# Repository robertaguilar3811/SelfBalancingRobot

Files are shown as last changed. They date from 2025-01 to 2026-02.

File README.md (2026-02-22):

# Self Balancing Robot

> **Status:** Active development  
> This project is under active development and is being used as a platform to study
industrial-style motion control, feedback systems, and real-time architecture.
---

## Overview

A two-wheeled self-balancing robot built as a controls engineering exercise, with emphasis on deterministic control loops, state-based logic, and clean separation of real-time and supervisory tasks.

The design philosophy mirrors industrial automation: clearly defined I/O, cyclic execution, and closed-loop control driven by sensor feedback applied here to a dynamic, inherently unstable mechanical system.

---

## Mechanical Design

The frame consists of stacked 3D-printed PLA plates constrained by 3/8"-16 threaded rods, forming a rigid, modular structure that allows:

- Rapid iteration and reconfiguration
- Controlled center-of-mass adjustment
- Easy access to wiring, sensors, and drive components

---

## Hardware

| Component | Role |
|---|---|
| Teensy 4.1 | Low-level motor controller |
| Raspberry Pi 4 | Soft PLC — runs CodeSys runtime |
| MPU6050 IMU | Orientation and angular rate feedback |
| DC Gear Motors | Primary actuators |

The Teensy handles time-critical motor control while the Raspberry Pi runs a CodeSys soft PLC runtime, handling supervisory logic, configuration, and monitoring a direct implementation of a PLC + distributed I/O architecture found in industrial systems.

---

## Control Strategy

The robot stabilizes using a closed-loop feedback controller driven by tilt angle and angular velocity from the IMU. Key design principles include:

- Deterministic cyclic execution
- Tunable feedback control loop
- Clear separation of control and supervisory logic
- Defined safe startup and shutdown behavior

Currently implemented as a PID controller, with planned migration to more advanced control strategies as the platform matures.

---

## Software Structure

Control software is organized around industrial automation principles:

- Cyclic main control loop with fixed execution timing
- Explicit state machine (Init → Idle → Enable → Run → Fault)
- Deterministic sensor acquisition and actuator output
- Parameterized gains and configurable limits

Monitoring and tuning are handled outside the real-time loop to preserve control determinism.

---

## System State Machine

| State | Description |
|---|---|
| Init | Hardware and sensor validation |
| Idle | Motors disabled, system safe |
| Enable | Control loop armed, awaiting command |
| Run | Active balancing control |
| Fault | Safe shutdown on error or instability |

---

## Planned Improvements

- Port control logic concepts to PLC platforms (Structured Text / IEC 61131-3)
- Gain scheduling and advanced control strategies
- Enhanced fault diagnostics and recovery
- Industrial HMI or supervisory system integration

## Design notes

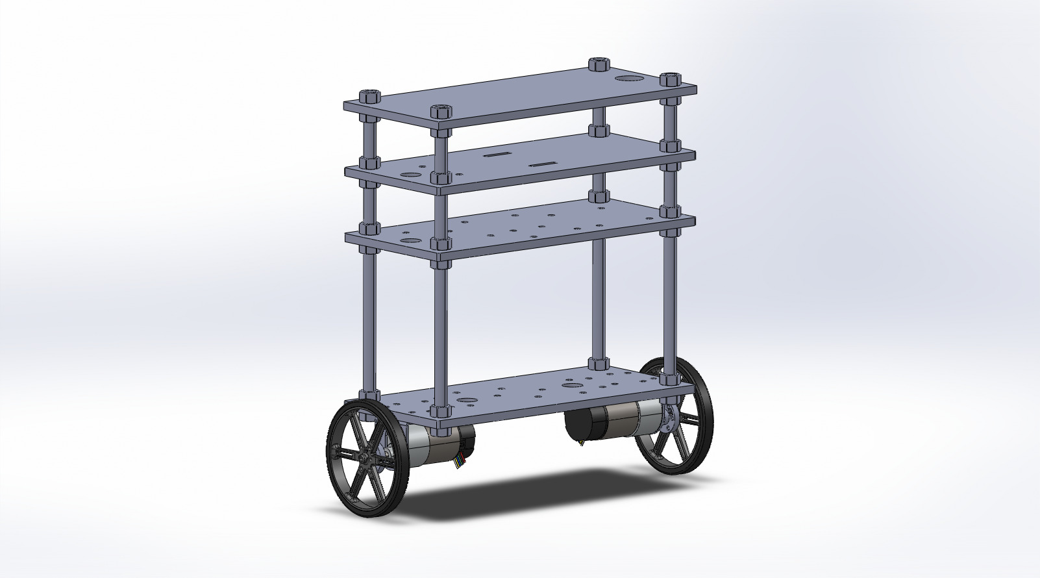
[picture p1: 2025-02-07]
asm.jpg

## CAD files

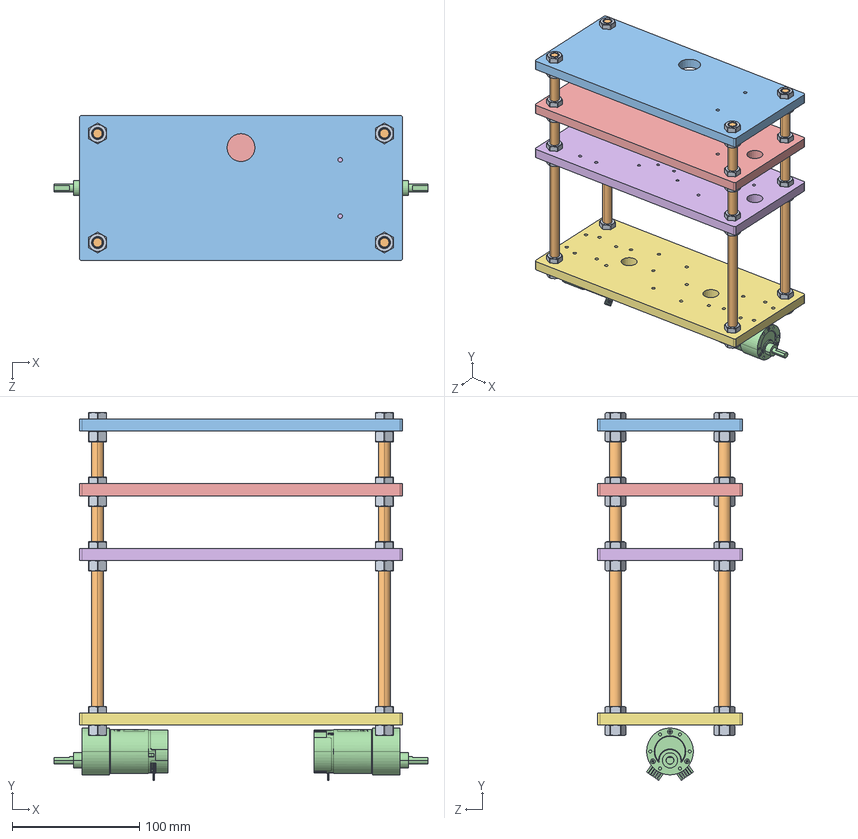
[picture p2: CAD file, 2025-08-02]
CAD/asm.SLDASM
294.0 x 289.3 x 114.3 mm
BOTTOM PLATE, SELF BALANCING ROBOT
MIDDLE BOTTOM PLATE, SELF BALANCING ROBOT
MIDDLE TOP PLATE, SELF BALANCING ROBOT
37D-GEARMOTOR-19-30-ENCODER x 2
TOP PLATE, SELF BALANCING ROBOT
95475A660-THREADED ROD, .375-16 THD., 10.000 LNG. x 4
90473A031-NUT, .375-16 THD. x 31

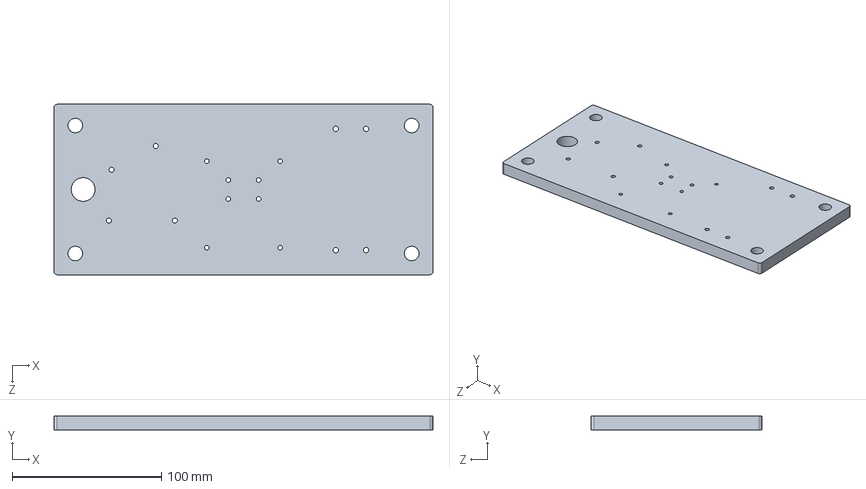
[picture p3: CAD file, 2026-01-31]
CAD/MIDDLE BOTTOM PLATE, SELF BALANCING ROBOT.SLDPRT
254.0 x 9.53 x 114.3 mm

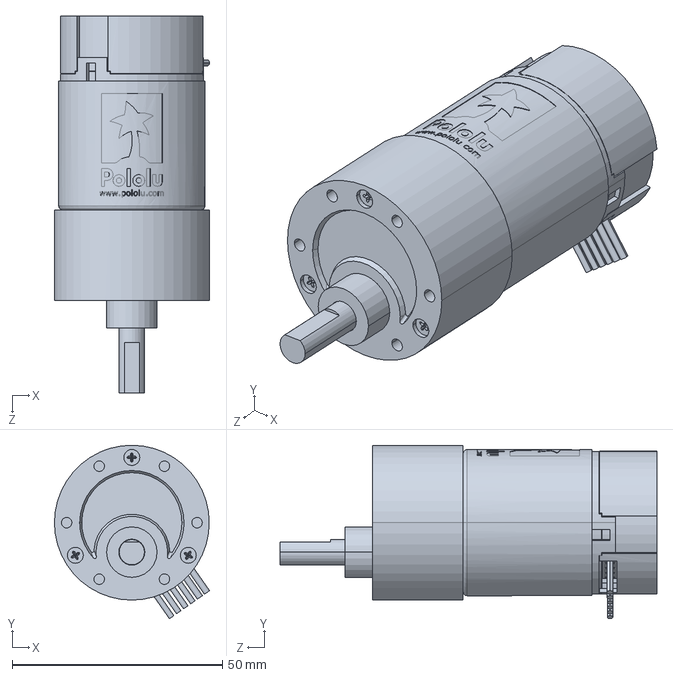
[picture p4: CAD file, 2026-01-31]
CAD/Pololu Components/37D-GEARMOTOR-19-30-ENCODER.SLDPRT
36.9 x 41.2 x 89.6 mm

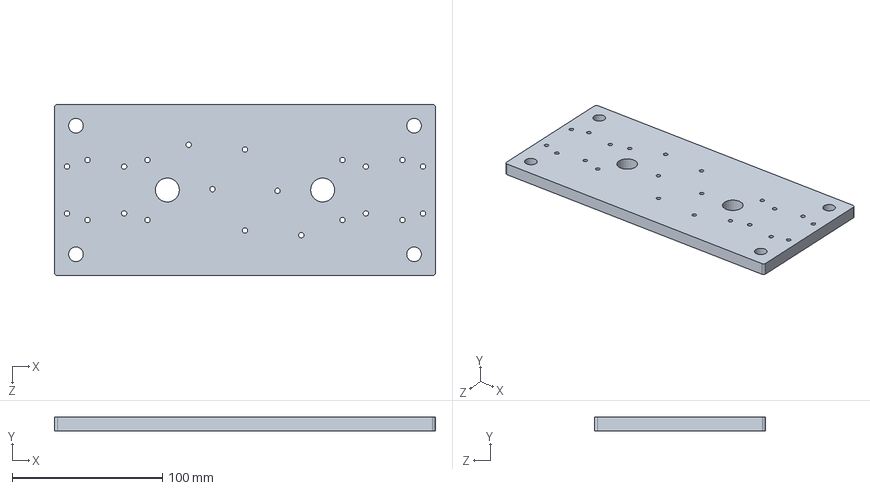
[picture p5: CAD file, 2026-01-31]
CAD/BOTTOM PLATE, SELF BALANCING ROBOT.SLDPRT
254.0 x 9.53 x 114.3 mm

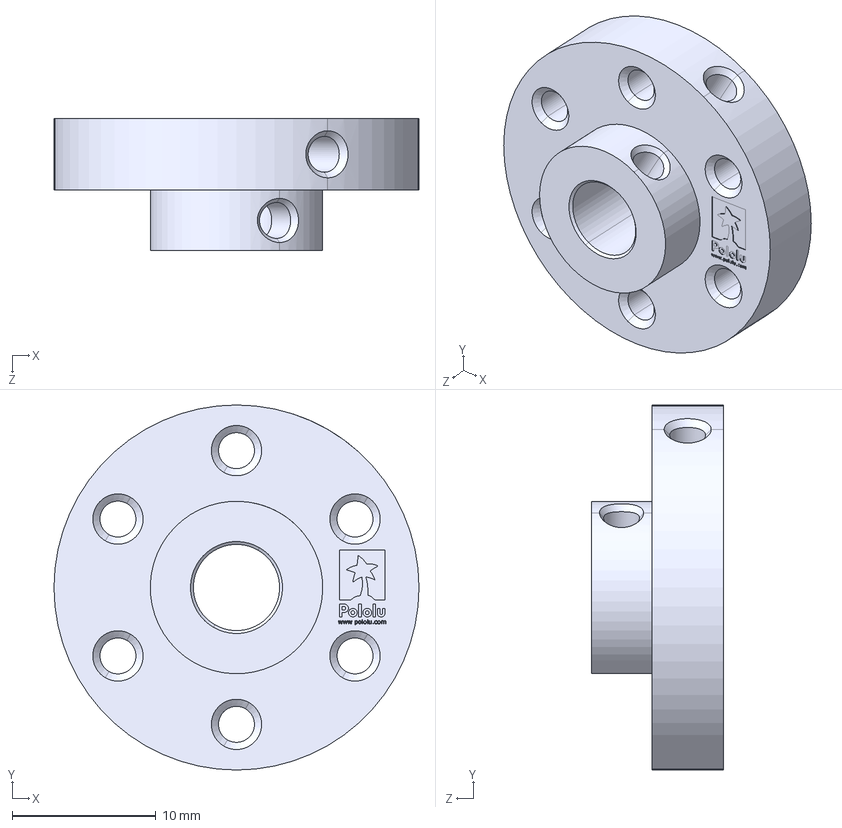
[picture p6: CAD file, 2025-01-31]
CAD/Pololu Components/POLOLU MOUNTING HUB FOR 6MM SHAFT, M3 HOLES.step
25.4 x 25.4 x 9.20 mm

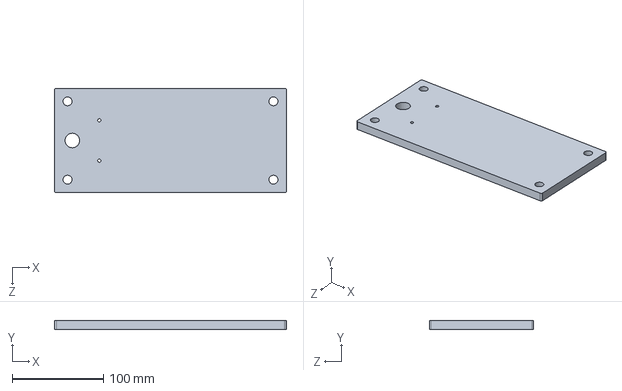
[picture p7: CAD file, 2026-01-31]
CAD/MIDDLE TOP PLATE, SELF BALANCING ROBOT.SLDPRT
254.0 x 9.53 x 114.3 mm

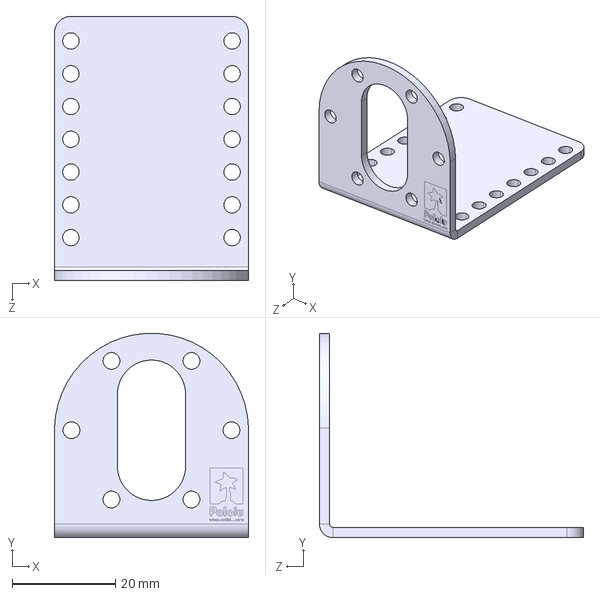
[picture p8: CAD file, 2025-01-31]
CAD/Pololu Components/POLOLU L-BRACKET FOR 37D-GEARMOTOR.step
37.6 x 39.6 x 51.2 mm

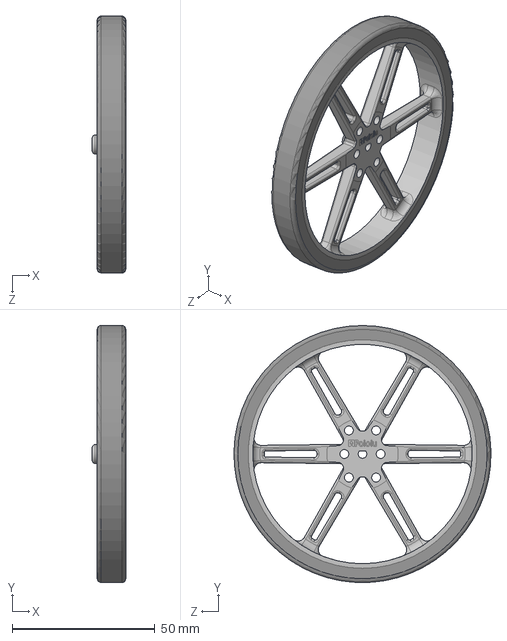
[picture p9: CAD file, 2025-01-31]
CAD/Pololu Components/POLOLU WHEEL, 90MM X 10MM.step
11.8 x 90.0 x 90.0 mm

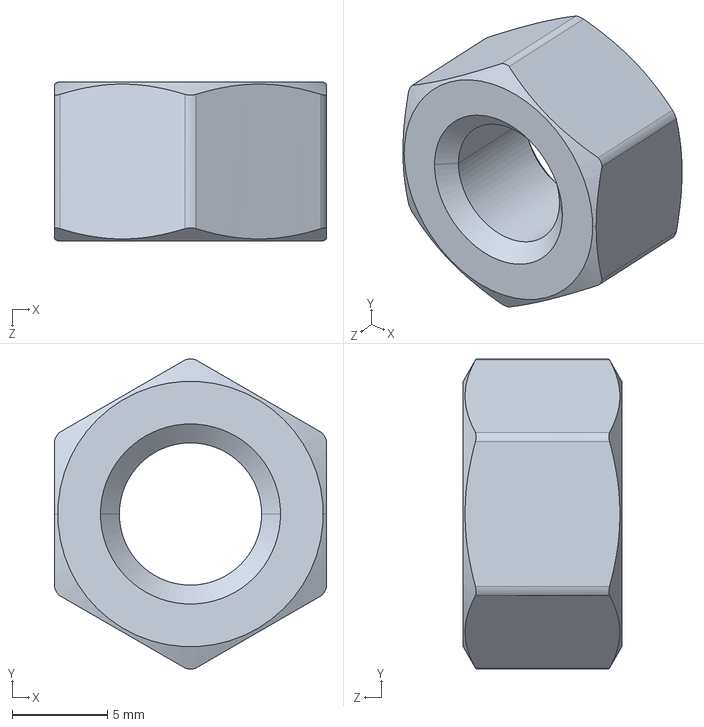
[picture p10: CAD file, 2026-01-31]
CAD/Hardware/90473A031-NUT, .375-16 THD..SLDPRT
14.3 x 16.3 x 8.33 mm

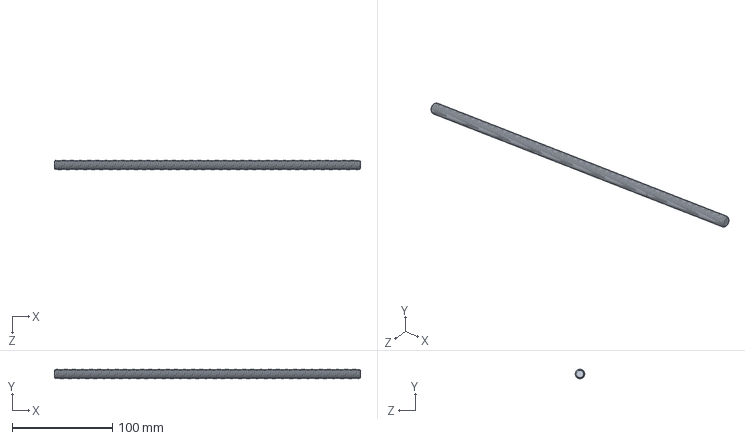
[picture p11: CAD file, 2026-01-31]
CAD/Hardware/90034A056-THREADED ROD, .375-16 THD., 12.000 IN LNG..SLDPRT
304.8 x 9.53 x 9.53 mm

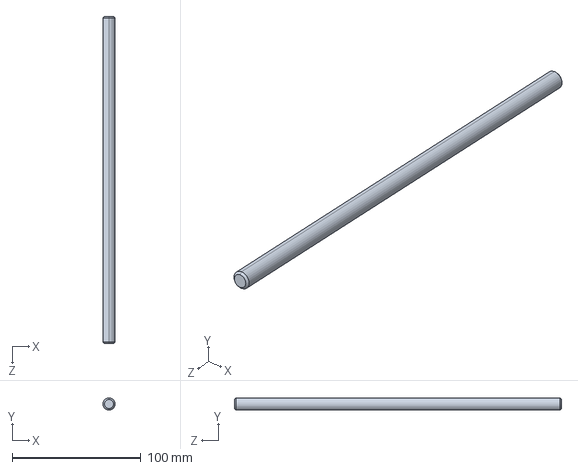
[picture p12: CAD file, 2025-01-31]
CAD/Hardware/95475A660-THREADED ROD, .375-16 THD., 10.000 LNG..SLDPRT
9.53 x 9.53 x 254.0 mm

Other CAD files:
CAD/TOP PLATE, SELF BALANCING ROBOT.SLDPRT
CAD/BOTTOM PLATE, SELF BALANCING ROBOT.STL
CAD/MIDDLE BOTTOM PLATE, SELF BALANCING ROBOT.STL
CAD/MIDDLE TOP PLATE, SELF BALANCING ROBOT.STL
CAD/Pololu Components/POLOLU L-BRACKET FOR 37D-GEARMOTOR.SLDPRT
CAD/Pololu Components/POLOLU MOUNTING HUB FOR 6MM SHAFT, M3 HOLES.SLDPRT
CAD/Pololu Components/POLOLU WHEEL, 90MM X 10MM.SLDPRT
CAD/TOP PLATE, SELF BALANCING ROBOT.STL

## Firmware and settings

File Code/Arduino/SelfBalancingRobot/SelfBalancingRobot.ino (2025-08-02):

#include <Wire.h>
#include "SparkFun_BNO080_Arduino_Library.h"
#include <SimpleKalmanFilter.h>
#include <PID_v1.h>

BNO080 myIMU;

#define DIRECT 0
#define REVERSE 1

double Setpoint = 0;
double delta = 0.1;
double lowSetpoint = Setpoint - delta;
double highSetpoint = Setpoint + delta;

double pitch = 0.0;
double pitchFiltered = 0.0;
double offset = 4.7; //2.78

double Output = 0.0;

double Kp = 3;
double Ki = 1.5;
double Kd = 2.5;

PID myPID(&pitchFiltered, &Output, &Setpoint, Kp, Ki, Kd, DIRECT);

int LEFT_RPWM = 3;
int LEFT_LPWM = 4;
int RIGHT_RPWM = 7;
int RIGHT_LPWM = 8;

int LEFT_L_EN = 1;
int LEFT_R_EN = 2;
int RIGHT_L_EN = 5;
int RIGHT_R_EN = 6;

SimpleKalmanFilter simpleKalmanFilter(0.085, 0.085, 0.1);

const long SERIAL_REFRESH_TIME = 100;
long refresh_time;

void setup() {

  Serial.begin(115200);
  Wire.begin();

  pinMode(LEFT_RPWM, OUTPUT);
  pinMode(LEFT_LPWM, OUTPUT);
  pinMode(RIGHT_RPWM, OUTPUT);
  pinMode(RIGHT_LPWM, OUTPUT);
  pinMode(LEFT_L_EN, OUTPUT);
  pinMode(LEFT_R_EN, OUTPUT);
  pinMode(RIGHT_L_EN, OUTPUT);
  pinMode(RIGHT_R_EN, OUTPUT);

  digitalWrite(LEFT_R_EN, HIGH);  
  digitalWrite(LEFT_L_EN, HIGH);
  digitalWrite(RIGHT_R_EN, HIGH);  
  digitalWrite(RIGHT_L_EN, HIGH);

  if (myIMU.begin() == false) {
  Serial.println(F("BNO080 not detected at default I2C address. Check your jumpers and the hookup guide. Freezing..."));
  while (1);
  }
  Wire.setClock(400000); //Increase I2C data rate to 400kHz
  myIMU.enableRotationVector(50); //Send data update every 50ms

  myPID.SetMode(AUTOMATIC); 
  }

void calculateAngle() {
    if (myIMU.dataAvailable() == true) {
        pitch = (myIMU.getPitch()) * 180.0 / PI;     // Update global pitch variable
        pitch = pitch + offset; //remove offset
    }
}

void filterAngle(){
  pitchFiltered = simpleKalmanFilter.updateEstimate(pitch);
  //pitchFiltered = pitch + offset;   //remove offset
}

void moveForward(int speed) {
  analogWrite(RIGHT_RPWM, speed);  // Right motor forward
  analogWrite(RIGHT_LPWM, 0);      // Right motor off
  
  analogWrite(LEFT_LPWM, speed);   // Left motor forward
  analogWrite(LEFT_RPWM, 0);       // Left motor off

  //Serial.println("\t");
  //Serial.print("Direction: Forward");
  //Serial.print(", ");
  //Serial.print("Output: ");
  //Serial.print(speed);
}

void moveBackward(int speed) {
  analogWrite(RIGHT_RPWM, 0);      // Right motor off
  analogWrite(RIGHT_LPWM, speed);  // Right motor reverse
  
  analogWrite(LEFT_RPWM, speed);       // Left motor off
  analogWrite(LEFT_LPWM, 0);   // Left motor reverse

  //Serial.println("\t");
  //Serial.print("Direction: Reverse");
  //Serial.print(", ");
  //Serial.print("Output: ");
  //Serial.print(speed);
}

void stopMoving() {
  analogWrite(RIGHT_RPWM, 0);
  analogWrite(RIGHT_LPWM, 0);
  analogWrite(LEFT_RPWM, 0);
  analogWrite(LEFT_LPWM, 0);

  //Serial.println("\t");
  //Serial.print("Direction: None");
  //Serial.print(", ");
  //Serial.print("Output: 0");
  
}

void loop() {

  calculateAngle();
  filterAngle();

  Output = constrain(Output, 20, 255); //30

  if (pitchFiltered < lowSetpoint && pitchFiltered > -45){
    myPID.SetControllerDirection(DIRECT);
    myPID.Compute();
    moveBackward(Output);
  }
  else if (pitchFiltered > highSetpoint && pitchFiltered < 45){
    myPID.SetControllerDirection(REVERSE);
    myPID.Compute();
    moveForward(Output);
  }
  else{
    stopMoving();
  }
  
  //Serial.print("Angle:");
  //Serial.print(pitch);
  //Serial.print(",");
  //Serial.print("Filtered Angle:");
  //Serial.println(pitchFiltered);
  
}

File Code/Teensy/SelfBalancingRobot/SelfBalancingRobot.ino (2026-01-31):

#include <Wire.h>

#define I2C_ADDRESS 0x58

// Enable pins
const int LEFT_L_EN  = 2;
const int LEFT_R_EN  = 3;
const int RIGHT_L_EN = 6;
const int RIGHT_R_EN = 7;

// PWM pins
const int LEFT_R_PWM  = 4;
const int LEFT_L_PWM  = 5;
const int RIGHT_R_PWM = 8;
const int RIGHT_L_PWM = 9;

// Stored values
uint8_t left_r_pwm  = 0;
uint8_t left_l_pwm  = 0;
uint8_t right_r_pwm = 0;
uint8_t right_l_pwm = 0;

bool left_r_en  = false;
bool left_l_en  = false;
bool right_r_en = false;
bool right_l_en = false;

void setup() {
  Serial.begin(115200);
  Wire.begin(I2C_ADDRESS);
  Wire.onReceive(receiveEvent);

  // Set pins
  pinMode(LEFT_R_EN, OUTPUT);
  pinMode(LEFT_L_EN, OUTPUT);
  pinMode(RIGHT_R_EN, OUTPUT);
  pinMode(RIGHT_L_EN, OUTPUT);

  pinMode(LEFT_R_PWM, OUTPUT);
  pinMode(LEFT_L_PWM, OUTPUT);
  pinMode(RIGHT_R_PWM, OUTPUT);
  pinMode(RIGHT_L_PWM, OUTPUT);
}

void loop() {
  // Apply enable signals
  digitalWrite(LEFT_R_EN,  left_r_en  ? HIGH : LOW);
  digitalWrite(LEFT_L_EN,  left_l_en  ? HIGH : LOW);
  digitalWrite(RIGHT_R_EN, right_r_en ? HIGH : LOW);
  digitalWrite(RIGHT_L_EN, right_l_en ? HIGH : LOW);

  // Apply PWM signals
  analogWrite(LEFT_R_PWM,  left_r_pwm);
  analogWrite(LEFT_L_PWM,  left_l_pwm);
  analogWrite(RIGHT_R_PWM, right_r_pwm);
  analogWrite(RIGHT_L_PWM, right_l_pwm);

  delay(10); // 100 Hz update
  Serial.print("LEFT_R_EN: ");
  Serial.println(left_r_en);
  delay(10);
  Serial.print("LEFT_L_EN: ");
  Serial.println(left_l_en);
  //Serial.println(left_r_pwm);
  //Serial.println(left_l_pwm);
}

// Receive I2C data from CODESYS
void receiveEvent(int howMany) {
  while (Wire.available() >= 2) {
    uint8_t reg = Wire.read();
    uint8_t val = Wire.read();

    switch (reg) {
      case 0x00: left_r_en  = val != 0; break;
      case 0x01: left_l_en  = val != 0; break;
      case 0x02: right_r_en = val != 0; break;
      case 0x03: right_l_en = val != 0; break;
      case 0x04: right_r_pwm = val; break;
      case 0x05: right_l_pwm = val; break;
      case 0x06: left_r_pwm  = val; break;
      case 0x07: left_l_pwm  = val; break;
    }
  }
}

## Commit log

2025-01-30 added arduino code
2025-01-30 added CAD folder
2025-01-31 added CAD files
    [37D-GEARMOTOR-19-30-ENCODER.SLDPRT, 90473A031-NUT, .375-16 THD..SLDPRT, 95475A660-THREADED ROD, .375-16 THD., 10.000 LNG..SLDPRT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]
2025-01-31 organized folders
    [37D-GEARMOTOR-19-30-ENCODER.SLDPRT, 90473A031-NUT, .375-16 THD..SLDPRT, 95475A660-THREADED ROD, .375-16 THD., 10.000 LNG..SLDPRT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]
2025-01-31 updated CAD
    [asm.SLDASM]
2025-02-02 updated CAD files
    [asm.SLDASM]
2025-02-09 updated read me
    [asm.SLDASM]
2025-02-09 updated PID gains
2026-01-05 teensy i2c write and read works
    [37D-GEARMOTOR-19-30-ENCODER.SLDPRT, 90034A056-THREADED ROD, .375-16 THD., 12.000 IN LNG..SLDPRT, 90473A031-NUT, .375-16 THD..SLDPRT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]
2026-01-31 trying to fix gitignore
    [BOTTOM PLATE, SELF BALANCING ROBOT.SLDPRT, BOTTOM PLATE, SELF BALANCING ROBOT.STL, MIDDLE BOTTOM PLATE, SELF BALANCING ROBOT.SLDPRT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]
